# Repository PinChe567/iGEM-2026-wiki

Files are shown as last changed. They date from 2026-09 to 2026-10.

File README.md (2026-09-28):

# AeroSense Wiki · September 24 design edition

新版入口是 `index.html`。在此資料夾執行 `./preview.ps1` 可開啟本機預覽，網址為 `http://127.0.0.1:8000/index.html`；若 8000 已使用，可執行 `./preview.ps1 -Port 8001`。不需要安裝網站套件。

最新修正記錄在上一層的 `reports/06-3D影片與介面修正版.md`。目前首頁載入 `homepage_animation/` 中新的 v3 Blender 雙影片，滾輪對應播放進度；Description 直接使用可左右控制的 3D 旅程；Parts 使用可點選的 Blender 受器模型。正式發布前仍需完成 iGEM 影片託管及 URL 串接。

美術微調在 `css/refinement.css`，共用果蠅與影片在 `js/experience.js`。`models/blender/` 保存可編輯的 v3 `.blend` 和建模／渲染腳本。header/footer 的共用來源為 `templates/`，修改後執行上一層 `scripts/sync_shell.py`。研究內文與原始 Markdown 保留。`run_windows.ps1` 是下列舊 v2 Blender 工作流程，**不是網站預覽啟動器**。

---

# 原始 AeroSense Showcase v2 文件

這版針對目前 interactive 的主要問題重新設計 Blender scene：

- 果蠅改成 rear-dorsal chase 用模型，翅膀 pivot 與身體連在胸部。
- Warehouse 有貨架、咖啡袋、咖啡豆、木箱、燈具、障礙物、實際 VOC source。
- Olfaction 不再是一堆圈圈，而是一個 antenna/sensilla corridor + 明確 receptor gateway。
- Cell 是單一大型 HEK293T-like cell chamber，含 receptor、Ca²⁺ 路徑、GCaMP signal。
- Hardware 是 sample chamber → PD → TIA → ADC → MCU 的 PCB 場景。
- Decoder 是 AL glomeruli → projection → sparse KC field，不再用不明圓圈。
- Return 回到 stored-food application。

## 執行

直接雙擊 `run_windows.bat`，或 PowerShell：

```powershell
powershell -ExecutionPolicy Bypass -File .\run_windows.ps1
```

輸出位置：

```text
models/showcase_v2/aerosense_fly_v2.glb
models/showcase_v2/aerosense_01_warehouse_v2.glb
models/showcase_v2/aerosense_02_olfaction_v2.glb
models/showcase_v2/aerosense_03_cell_v2.glb
models/showcase_v2/aerosense_04_hardware_v2.glb
models/showcase_v2/aerosense_05_decoder_v2.glb
models/showcase_v2/aerosense_06_return_v2.glb
models/previews_v2/*.png
models/blender/AeroSense_Showcase_v2.blend
```

生成後，把 `CURSOR_PROMPT_V2.txt` 給 Cursor，讓它把新版模型、穩定 chase camera、manual/autopilot、real-time score、stage dive、文字動畫一起接進前端。

> 注意：此環境無 Blender runtime，因此腳本已做 Python syntax check，但最終 render/API 相容性仍需你本機 Blender 跑一次。若有 Blender 5.2 API error，把完整 traceback 貼回來即可修。

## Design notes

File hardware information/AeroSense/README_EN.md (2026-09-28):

# AeroSense engineering package

Start here, then read `docs/EN/Assembly_Manual_EN.pdf`. This is a reproducible engineering prototype with executed simulations, compiled firmware and an operable demo UI. The PCB is not fabricated. Board operation, biological compatibility and odor-recognition performance have not been established.

## Files

|Purpose|Location|
|---|---|
|Print meshes, CAD, drawings|`STL/`, `CAD/`, `docs/EN/Design_Drawings_EN.pdf`|
|Simulation analysis and numerical results|`docs/EN/Simulation_Analysis_EN.pdf`, `results/`|
|Reproduce calculations/figures/movies|`reproduce.py`, `simulation/`, `requirements.txt`|
|Printed, purchased and PCB BOM|`BOM/BOM_EN.xlsx`|
|Assembly|`docs/EN/Assembly_Manual_EN.pdf`|
|UI, firmware, server|`software/`, `docs/EN/Software_Guide_EN.pdf`|
|Operation, normalization, performance|`docs/EN/Operating_Protocols_EN.pdf`|
|Feedback form|`docs/EN/User_Feedback_EN.pdf`|

Each document has Chinese and editable Markdown versions. `manifest.json` provides SHA-256 hashes. Original vendor PDFs and papers are referenced, not redistributed.

## Quick start

Run `python software/server/server.py --demo` from the package root. On the same computer, open `http://127.0.0.1:8765`, enter API key `local-demo-key`, connect and start. All records are explicitly DEMO. This does not operate a PCB.

Print one well for dimensional/material screening before committing to the large enclosure. The baseline has eight parts. The accessible cap replaces one cap with two, giving nine operating prints. Do not purchase both configurations as additive assemblies.

Ask the vendor to complete `validation/fit_measurements.csv` and provide a populated STEP model. Nominal fit is not guaranteed physical clearance. Start electronics with LEDs off; only set `BOARD_VALIDATED=true` after measured power, ADC and LED-waveform checks.

## Materials

|Part|Quantity|Resin|
|---|---:|---|
|01 body, 03 lid, 04 cap|1 each|Rigid PC/GF-like Black|
|02 tray|1|Aqua 8K Gray|
|05 monolithic wells|4|Aqua Clear Plus; fit/material test only, not qualified for direct HEK293T culture|

Both well-floor surfaces are flat, 0.5 mm thick; nominal fill is 150 uL. Flat floors do not ensure uniform illumination. Polishing does not remove bulk purple absorption or autofluorescence; measure transmission/background at the relevant excitation/emission wavelengths and change materials or culture-vessel architecture if unacceptable.

## Reproduction

Python 3.12 is recommended. Install `python -m pip install -r requirements.txt` in an isolated environment. From the extracted root:

```text
python reproduce.py --out ../AeroSense_replot --plots
python reproduce.py --out ../AeroSense_movies --video
python reproduce.py --out ../AeroSense_optics --optics
python reproduce.py --out ../AeroSense_flow --flow --engine csharp --workers 2
python reproduce.py --out ../AeroSense_cad --cad
```

`--out` must be a new directory. Full optical/CFD calculations can be lengthy. CFD runs 27 plate cases plus one no-plate control. The Windows C# accelerator builds from included source using the .NET Framework compiler. Use `--engine numpy` elsewhere, with lower speed. CAD requires OpenSCAD; a non-default location can be supplied to `python CAD/build.py --out new_directory --openscad executable_path`. The CAD combines parametric CSG and canonical meshes; it is not a fully parametric reconstruction of the vendor PCB.

Additional baseline mesh refinement (0.3/0.2 mm results already included):

```text
python simulation/flow_sweep.py --case base --dx .3 --engine csharp --max-steps 60000
python simulation/flow_sweep.py --case base --dx .2 --engine csharp --max-steps 60000
```

Converged files are resume-safe and skipped. Use a fresh output directory for genuine recalculation. Movies advect passive markers in stored steady fields, not time-dependent Navier–Stokes, cell shear, dissolution or growth.

Figure I estimates source-to-PD collection fraction; Figure J multiplies emission fluence rate by collection fraction. Neither is normalized arbitrarily to make the image resemble the paper. Different geometry, media and filters imply different fields and magnitudes.

## Evidence and limits

Executed: 24 optical conditions with three seeds, 247 collection-map points, 27 plate CFD cases plus control, 48 synthetic DLIA cases, UI/API/calibration/model code tests, firmware and LittleFS builds. Validation records distinguish these from physical testing.

All plate cases have higher mean four-well headspace speed than the no-plate control under the stated metric. Mesh independence is not established. Do not claim cell protection from these calculations.

PD offset is modeled, while its signed direction still requires vendor rotation/mirroring confirmation. Wells follow LEDs; they are not forced into exact 90-degree radial spacing about the PD. Four frequency amplitudes from one PD are LED channels, not automatically independent well signals. Measure the optical mixing matrix before unmixing.

The neural-network training/held-out-group/inference pipeline is supplied without a fabricated trained model or odor accuracy. Templates are under `software/templates/`. No cloud account or external deployment has been created; internet access requires HTTPS and authentication configuration.

Known partial device cost is TWD66,749–67,182 including this quote's allocated PCB design/setup. Essential optical/gas items and shared equipment remain unquoted; this is not a complete or production cost.

The package supports wiki design, methods and simulation evidence. Add real photographs, calibration curves, cell data, independent-batch evaluation and participant feedback before claiming demonstrated hardware performance. Select the team's publication licenses and check third-party rights before public release.

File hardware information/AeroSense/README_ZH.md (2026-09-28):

# AeroSense 完整工程交付

先讀本檔，再讀 `docs/ZH/Assembly_Manual_ZH.pdf`。本套件是可重現的工程原型：有實際執行的模擬、可編譯韌體和可操作示範 UI；PCB 尚未製造，沒有實板、細胞或氣味辨識效能驗證。不要把模型圖當成實物照片。

## 檔案入口

|工作|檔案|
|---|---|
|列印與設計|`STL/`、`CAD/`、`docs/ZH/Design_Drawings_ZH.pdf`|
|光學、氣流與 DLIA 結果|`docs/ZH/Simulation_Analysis_ZH.pdf`、`results/`|
|重跑與重畫|`reproduce.py`、`simulation/`、`requirements.txt`|
|採購、列印材料、PCB 子料|`BOM/BOM_ZH.xlsx`；四個工作表分開，不重複計入 PCB 報價|
|組裝|`docs/ZH/Assembly_Manual_ZH.pdf`|
|手機 UI、ESP32、伺服器|`software/`、`docs/ZH/Software_Guide_ZH.pdf`|
|操作、校正與性能驗證|`docs/ZH/Operating_Protocols_ZH.pdf`|
|使用者回饋|`docs/ZH/User_Feedback_ZH.pdf`|

每份文件都有英文版與可編輯 Markdown；`manifest.json` 可核對檔案 SHA-256。使用者來源 PDF/論文本身沒有重新散布。

## 最快開始

1. 先執行手機介面的示範：在套件根目錄執行 `python software/server/server.py --demo`，以同一台電腦瀏覽 `http://127.0.0.1:8765`，API key 輸入 `local-demo-key`。資料明確標記 DEMO，沒有連到實板。
2. 先印四井中的一個作尺寸／材料測試，再印大殼。預設共八件；可拆洗內蓋用兩件取代一件，總共九件。兩套內蓋不能同時累加採購。
3. 給廠商 `validation/fit_measurements.csv`，取得含元件 STEP、LED/PD 方向與最高點；尚無法保證「一定不撞件」。
4. 依操作流程先暗訊號、電子假負載、無細胞螢光標準，再做材料／细胞驗證。預設韌體只允許 LED 全關的暗量測；量測供電、ADC 與 LED 波形後才設定 `BOARD_VALIDATED=true`。

## 樹脂與列印數量

|零件|數量|樹脂|
|---|---:|---|
|01 殼體、03 外蓋、04 內蓋|各 1|Rigid PC/GF-like Black|
|02 底托|1|Aqua 8K Gray|
|05 四個獨立一體 well|4|Aqua Clear Plus，僅供尺寸及材料試驗，未確認可直接培養 HEK293T|

Well 內外底面都平，底厚 0.5 mm，名目 150 µL。紫色樹脂的吸收與自身螢光不能用拋光消除；需實測 470/520 nm 相關光譜與空白，通不過就換經測試的透明材料或細胞培養容器方案。平底可減少厚度變化，但不保證照明均勻。

## 重現計算

建議 Python 3.12，在獨立環境安裝 `python -m pip install -r requirements.txt`。以下命令從解壓後根目錄執行。`--out` 指定尚不存在的新資料夾，保留交付資料：

```text
python reproduce.py --out ../AeroSense_replot --plots
python reproduce.py --out ../AeroSense_movies --video
python reproduce.py --out ../AeroSense_optics --optics
python reproduce.py --out ../AeroSense_flow --flow --engine csharp --workers 2
python reproduce.py --out ../AeroSense_cad --cad
```

光學全跑需要較長時間；保存種子與每次能量帳本。CFD 全跑是 27 組孔板加 1 組無孔板，不是阻力公式替代。Windows C# 加速器由附帶原始碼編譯，需要系統 .NET Framework C# compiler；其他平台可用 `--engine numpy`，速度較慢。OpenSCAD 是 CAD 外部依賴，預設 Windows 標準安裝位置；非標準路徑直接用 `python CAD/build.py --out 新資料夾 --openscad 執行檔路徑`。

CFD 已附 0.3/0.2 mm 基準網格結果。額外重算網格細化：

```text
python simulation/flow_sweep.py --case base --dx .3 --engine csharp --max-steps 60000
python simulation/flow_sweep.py --case base --dx .2 --engine csharp --max-steps 60000
```

已收斂檔案會跳過；需要真正重算時用新的 `--out` 資料夾。不要直接覆寫交付資料。影片使用保存的定常速度場推進被動標記；不是非定常流體解，也沒有求細胞剪力、氣味溶解或生長。

圖 I 對應點光源到 PD 的收集比例，圖 J 是發射光 fluence rate × 收集比例；沒有把結果各自除以最大值來「畫得像論文」。本設計幾何、介質和濾片與論文不同，圖形及量級不應被強迫相同。

## 目前證據與尚未完成的驗證

- 已執行：24 光學條件×3種子、247 點收光圖、27 孔板+無孔板 CFD、48 合成 DLIA 案例、UI/API/校正與模型程式測試、韌體及網頁檔案系統編譯。
- 孔板案例在四井上方平均速度指標上都高於無孔板對照；網格獨立性尚未成立，不能以此保證保護細胞。
- PD 偏移已納入；正負方向仍由廠商封裝旋轉／底視鏡像確認。四井以 LED 配準；沒有假裝四個井中心恰好在 PD 周圍每隔 90°。
- 單一 PD 的四頻數值是 LED 頻道，不自動等於四井獨立訊號。先量實際混合矩陣，再判斷能否可靠解混。
- 神經網路提供訓練／獨立批次留出／推論程式，不提供虛構已訓練模型或辨識準確率。範本在 `software/templates/`。
- 光學濾片、氣體濾器與轉接等仍未完整報價；BOM 明確標「待報價」。目前已知單機部分成本約 NT$66,749–67,182，包含 PCB 此次設計／開機分攤，不是量產價。
- 手機直連 ESP32 與伺服器兩種路徑都有程式。未建立外部雲端帳戶、未公開部署；遠端網路使用需依軟體指南配置 HTTPS 與金鑰。

本套件可作 wiki 的設計、方法及模擬證據；實物照片、校正曲線、細胞資料、跨批次模型評估與他人組裝問卷必須以真實實驗補齊。`validation/` 的通過項目不能改寫成整台機器已驗證。

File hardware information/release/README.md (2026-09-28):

# Release BOM

`AeroSense_Reader_BOM.csv` is published here only after `scripts/check_hardware_bom.py` passes.

The current `pcb v2/NTHU_TEST_BOARD_BOM.docx` is a draft. See `../BOM_SOURCE_AUDIT.md`. Do not link that DOCX as the final BOM.

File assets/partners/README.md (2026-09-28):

# Partner logos

Place **licensed, locally hosted** logo files in this folder.

Collaborators & Sponsors appear as reserved logo slots in the footer and on the homepage. Do **not** hotlink external logos. Do **not** invent a mark. Do **not** link the slots to Attributions.

When a licensed file exists, put it inside the matching slot:

```html
<figure class="footer-partners__slot">
  <img src="assets/partners/ist-group.png" alt="iST Group" width="180" height="72">
  <figcaption>iST Group</figcaption>
</figure>
```

Use `alt` = organization name. The hatched placeholder hides automatically when an `<img>` is present.

## Files still required

These organizations are named on the wiki. Logo files are **not** in the repository yet.

| Suggested filename | Organization |
| --- | --- |
| `ist-group.svg` or `ist-group.png` | iST Group |
| `nthu.svg` or `nthu.png` | National Tsing Hua University |

Optional, only after permission or a compatible license is on file:

| Suggested filename | Organization | Note |
| --- | --- | --- |
| `igem.svg` or `igem.png` | iGEM Foundation | Use only with iGEM brand permission |
| `fiti.svg` or `fiti.png` | FITI | Mentorship; confirm logo use |
| `garage-plus.svg` or `garage-plus.png` | NTHU Garage+ | Mentorship; confirm logo use |

Until a file exists, leave the reserved slot empty. Do not add a fake logo.

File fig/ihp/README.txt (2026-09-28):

AeroSense IHP image drop folder
===============================
Place consented, project-specific assets here. Do not add stock photos.

Expected filenames (see human-practices.html TODO(imagery) comments):
  people/taoyuan.webp
  people/farmers.webp
  people/enose.webp
  people/challenge-bioproducts.webp
  people/instrumentation.webp
  people/fiti.webp
  people/garageplus.webp
  people/exporters.webp
  hero-field-or-sensor.webp
  visit-taoyuan-annotated.webp
  mentor-fiti-bp-excerpt.webp
  mentor-fiti-pitch-excerpt.webp
  survey-*.webp (optional; HTML bars are primary)
  event-synbiobeta-poster.webp
  prototype-reader-bench.webp
  ui-risk-tier-shipped.webp (only if real UI exists)
  current-state.svg (optional export)
  problem-quant-sourced.svg (only with locked citation)

Each file needs: useful alt text in HTML, figcaption with context, credit/source, optimized size, lazy loading below the fold.

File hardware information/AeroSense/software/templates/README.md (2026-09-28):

D1–D4 are calibrated deltaF/F0 LED-channel features, not automatically unmixed wells.
Each group must represent an independent cell batch/day/device, never windows from the same exposure.
D1–D4 是 LED 通道 ΔF/F0；group 必須以獨立細胞批次／日期／設備分組，不能拆同一次刺激的時間窗。

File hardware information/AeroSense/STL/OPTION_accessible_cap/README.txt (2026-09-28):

Replace the one-piece 04 cap with BOTH files here: total operating prints = 9. Two M3x12 thumbscrews replace M3x10. Extra silicone ring: 22x19 outer,15x12 opening,0.8 stock compressed to0.6 mm. Cleaning/cure access improves, but biocompatibility and sealing are NOT validated. Do not print both cap options for one device.

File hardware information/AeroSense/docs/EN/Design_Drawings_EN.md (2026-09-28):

# Assembly and registration drawings

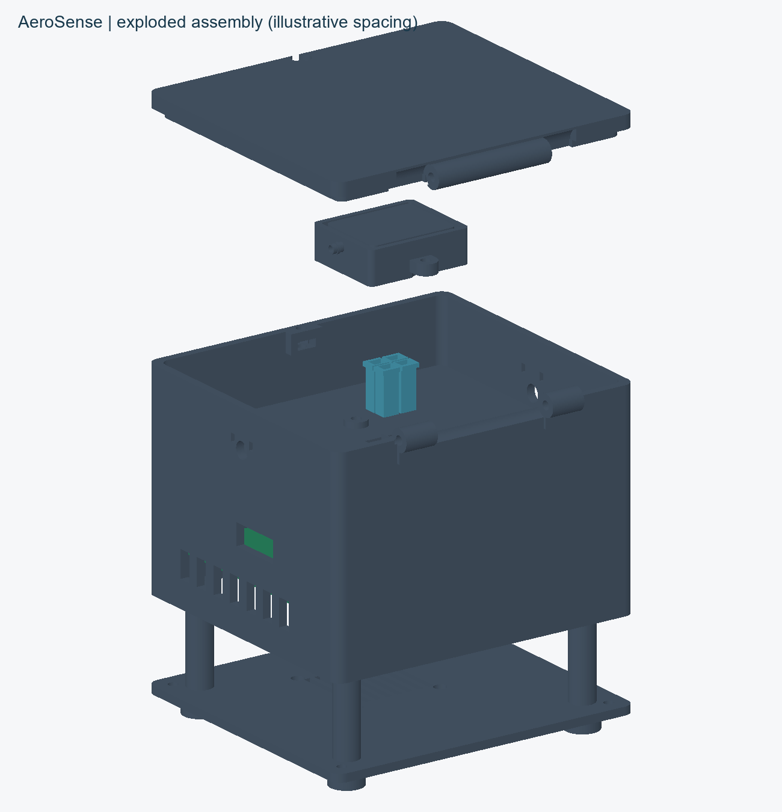
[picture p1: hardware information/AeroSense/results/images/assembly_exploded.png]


Exploded spacing is illustrative; actual placement is in CAD/assembly_coordinates and parts.json. Nominal overall bounds114 x109 x91 mm exclude hoses/fasteners. Units:mm. Part sheets show views/envelopes, not a complete GD&T manufacturing drawing.

# LED and PD optical registration

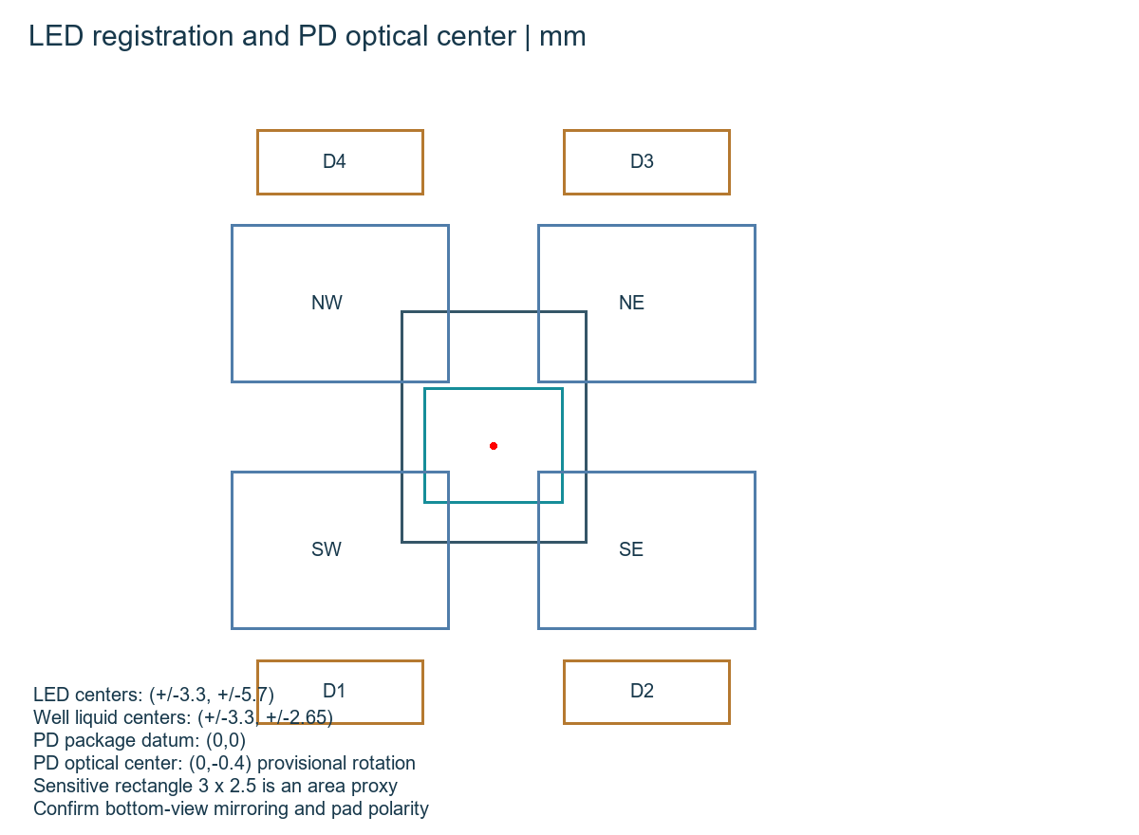
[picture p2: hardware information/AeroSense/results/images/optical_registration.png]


PD offset0.4 mm and LED-based well registration are independent. Package orientation, mounting holes and heights still require vendor STEP. Decimal display does not establish +/-0.01 mm accuracy.

# 01_integrated_body

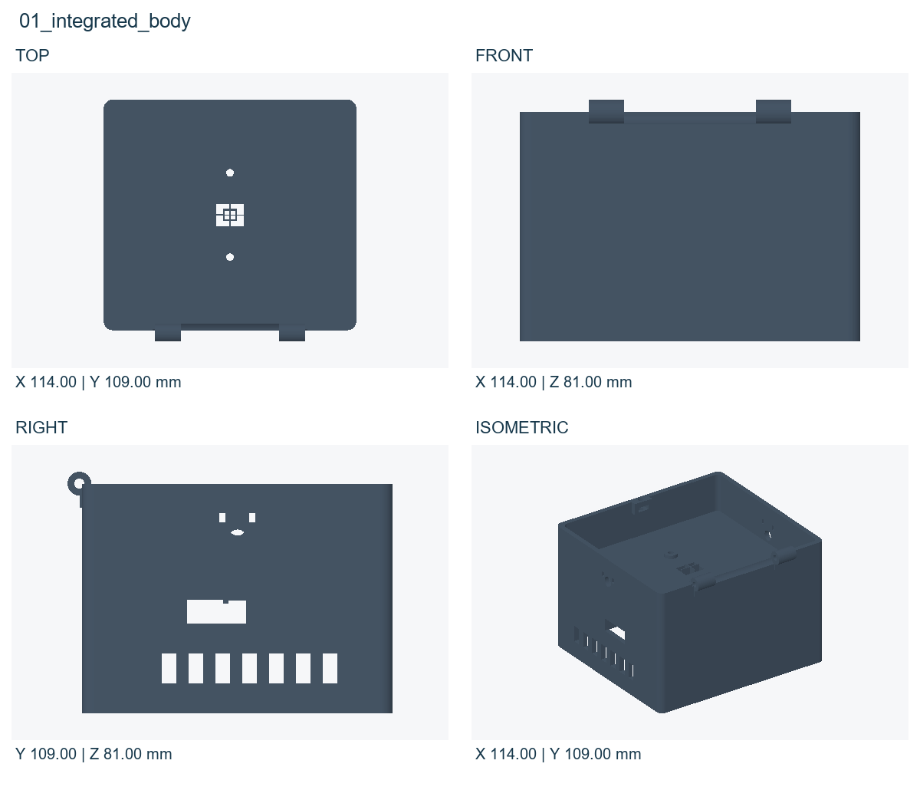
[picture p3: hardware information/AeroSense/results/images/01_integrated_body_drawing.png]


Material:PC_GF_BLACK. Assembly minimum(mm):[-57.0, -52.0, 3.0]. Printable STLs are translated to positive coordinates; do not assemble them by overlapping print origins.

# 02_service_tray

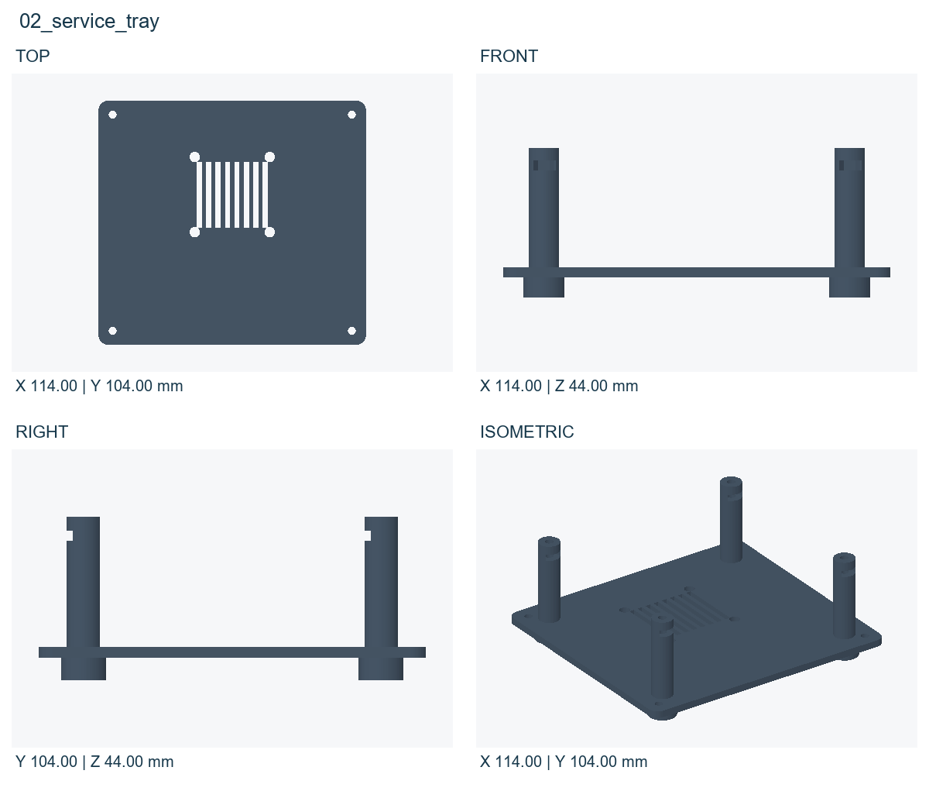
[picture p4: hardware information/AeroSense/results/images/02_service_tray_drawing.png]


Material:AQUA_8K_GRAY. Assembly minimum(mm):[-57.0, -52.0, -6.0]. Printable STLs are translated to positive coordinates; do not assemble them by overlapping print origins.

# 03_hinged_lid

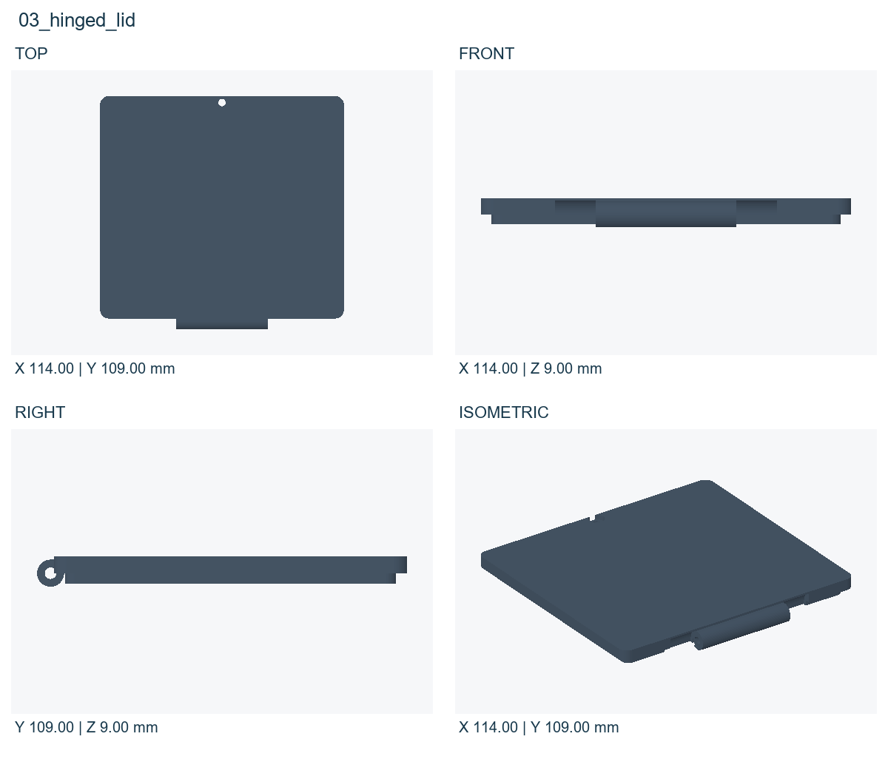
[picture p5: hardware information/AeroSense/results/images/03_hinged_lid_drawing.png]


Material:PC_GF_BLACK. Assembly minimum(mm):[-57.0, -52.0, 76.0]. Printable STLs are translated to positive coordinates; do not assemble them by overlapping print origins.

# 05_well_NE_CLEAR

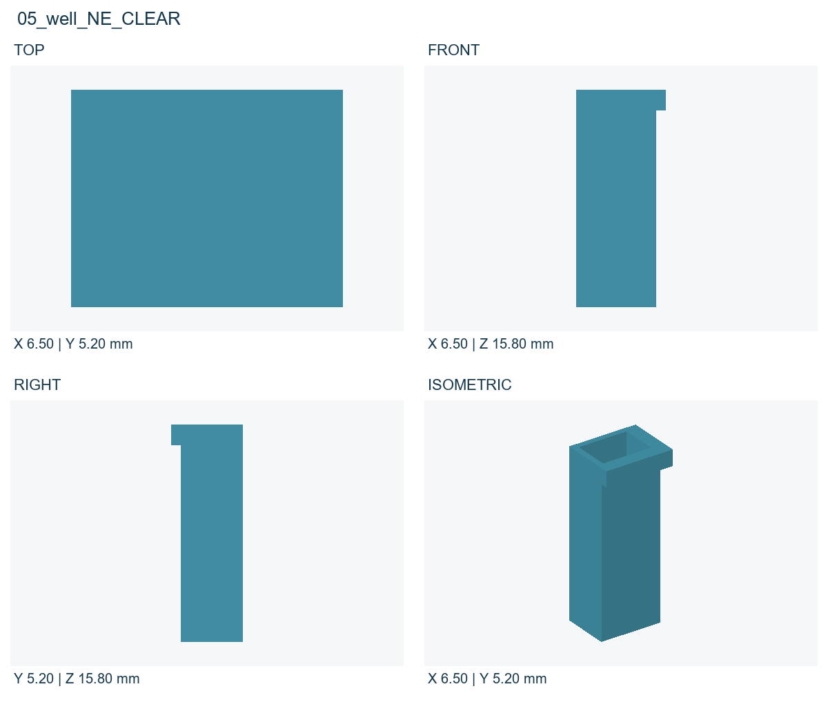
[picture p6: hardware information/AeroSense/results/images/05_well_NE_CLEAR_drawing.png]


Material:AQUA_CLEAR_PLUS_TEST_ONLY. Assembly minimum(mm):[0.4, 0.4, 42.5]. Printable STLs are translated to positive coordinates; do not assemble them by overlapping print origins.

# 05_well_NW_CLEAR

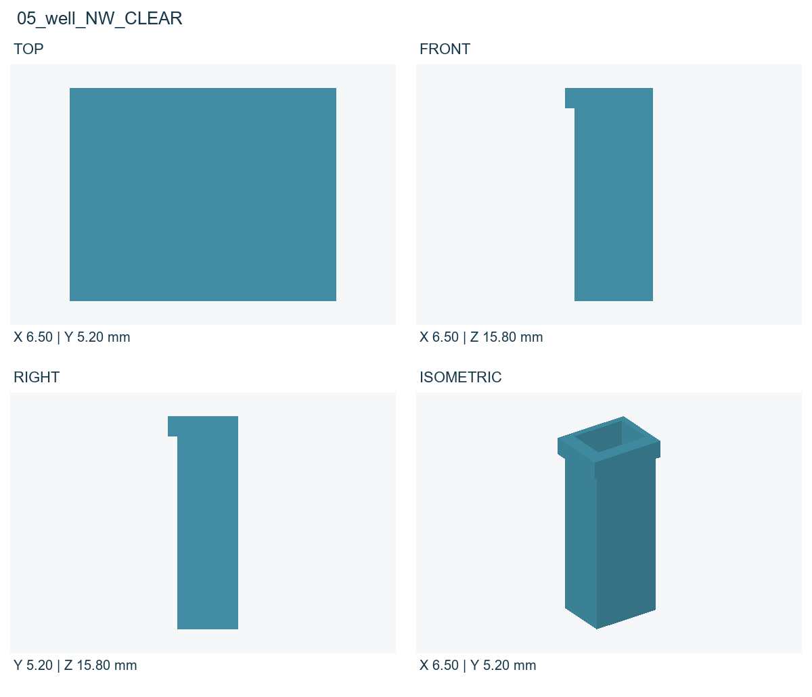
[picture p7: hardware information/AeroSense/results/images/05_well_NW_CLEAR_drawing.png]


Material:AQUA_CLEAR_PLUS_TEST_ONLY. Assembly minimum(mm):[-6.9, 0.4, 42.5]. Printable STLs are translated to positive coordinates; do not assemble them by overlapping print origins.

# 05_well_SW_CLEAR

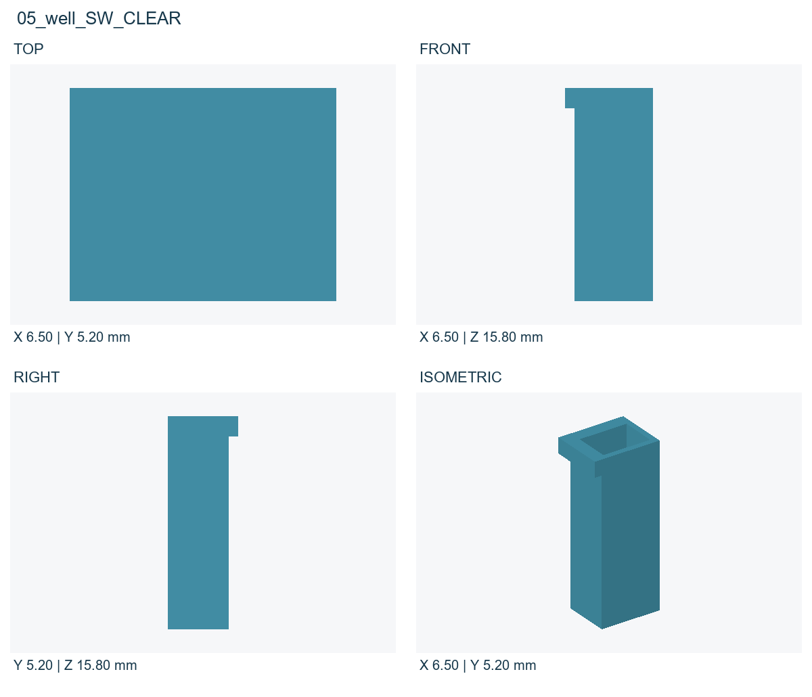
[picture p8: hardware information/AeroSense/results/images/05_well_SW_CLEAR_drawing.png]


Material:AQUA_CLEAR_PLUS_TEST_ONLY. Assembly minimum(mm):[-6.9, -5.6, 42.5]. Printable STLs are translated to positive coordinates; do not assemble them by overlapping print origins.

# 05_well_SE_CLEAR

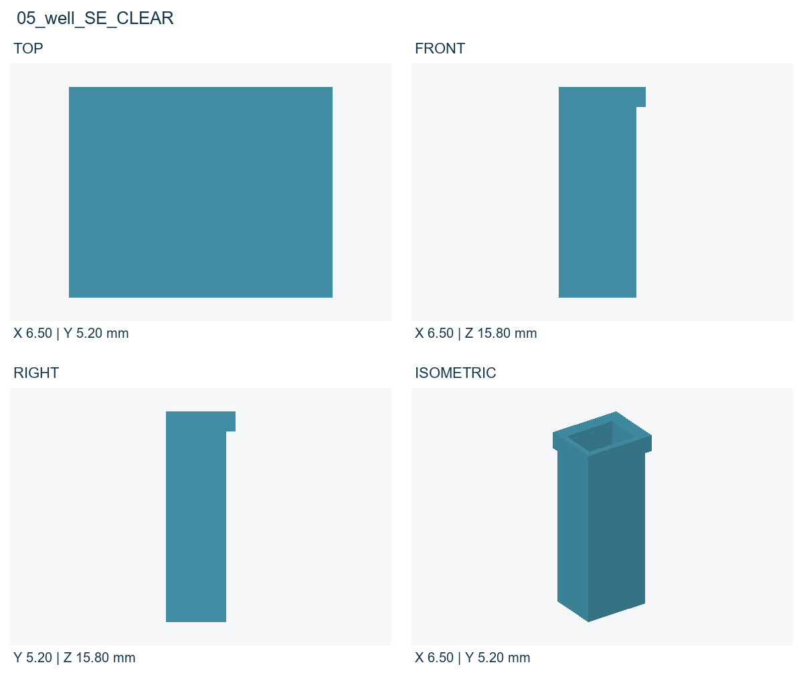
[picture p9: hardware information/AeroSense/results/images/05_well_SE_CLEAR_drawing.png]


Material:AQUA_CLEAR_PLUS_TEST_ONLY. Assembly minimum(mm):[0.4, -5.6, 42.5]. Printable STLs are translated to positive coordinates; do not assemble them by overlapping print origins.

# 04_common_gas_optical_cap

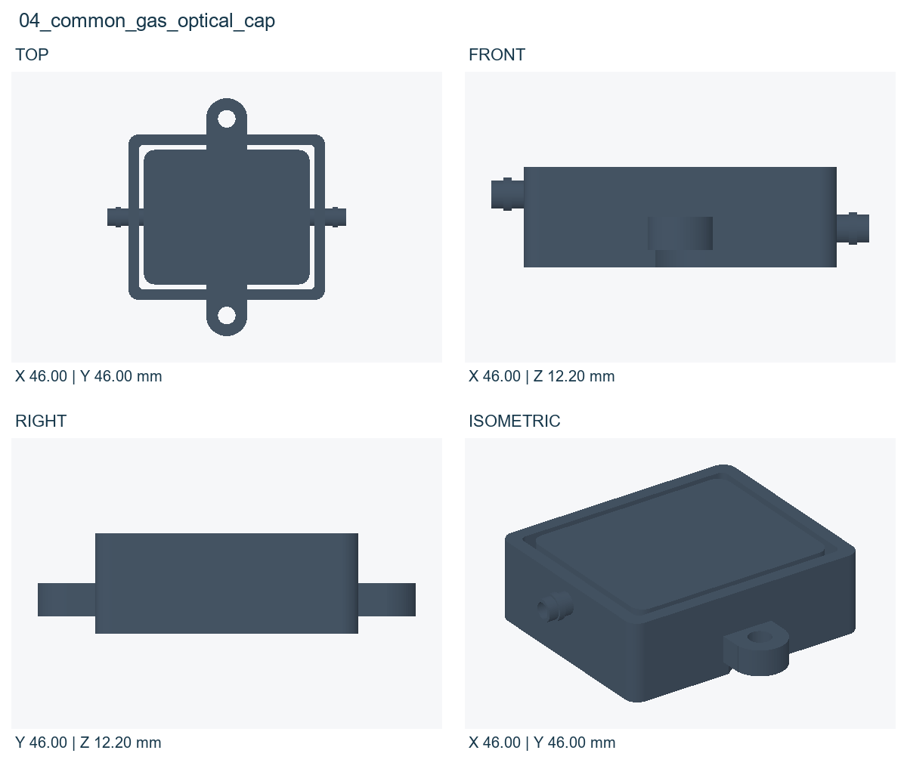
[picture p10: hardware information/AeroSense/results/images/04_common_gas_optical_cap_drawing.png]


Material:PC_GF_BLACK. Assembly minimum(mm):[-23.0, -23.0, 56.8]. Printable STLs are translated to positive coordinates; do not assemble them by overlapping print origins.

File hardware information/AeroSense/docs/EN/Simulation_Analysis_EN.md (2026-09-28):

# AeroSense engineering analysis

This report separates CAD, physical assumptions, numerical solutions and experimental evidence. Completed: flat-well STLs,24 photon-transport conditions,27 perforated-plate CFD cases plus no-plate control, spatial optical/acceptance maps,48 synthetic DLIA tests, phone UI and compiled ESP32 source. Pending: actual PCB operation, physical fit, sealing, resin/cell compatibility and odor-classification performance.



Conclusion: the PCB provides four LED gates and one16-bit ADC path for a four-frequency system. Adequate optical throughput, viable cells and independent well recovery still require experiments. Low part count and appearance do not substitute for validation.

# Geometry, optical center and tolerance



Wells register to the corresponding LED X coordinates and preserve clearance from dense components, rather than forming four equal round wells about the PD package center. Both well floors are planar with0.5 mm thickness and150 uL nominal fill. Flatness controls thickness but does not remove angular illumination, reflection or cell-distribution nonuniformity.

The Vishay drawing establishes a0.4 mm long-axis offset; the world sign depends on bottom-view mirroring and placement rotation. Main model:(0,-0.4), with(0,0),(0,+0.4), andX±0.2 sweeps. A3 x2.5 mm equal-area sensitive rectangle is used; the external3 x3 mm window is not assumed to be the active die. The nominal filter seat covers it, while gasket clipping needs measurement.

Four quadrants do not imply exactly90-degree spacing of well-center vectors, nor a fixed90-degree angle for every LED-cell-PD ray. Side excitation/downward collection is the design intent; the MC uses angular distributions.

# Optical method and correspondence to the paper

The plots follow Burton et al. Fig.2 I/J concepts, but that halo cannot be copied as this device result. Their miniature LED/PD, filter, dye solution and dimensions differ. This model uses millimeter resin wells and a20 um floor-cell layer.

η(r) is received power divided by power emitted by an isotropic point source, not peak normalization. Φ is weighted track-length per voxel volume, a scalar fluence rate in uW/mm2. J=Φ_em xη is the paper-style comparison. Source-position contribution uses q_em xη integrated over volume; these are different quantities and units.

Transport includes Beer-Lambert absorption, Henyey-Greenstein scattering, Fresnel refraction/reflection/TIR, diffuse opaque-wall reflection and two-stage fluorescence. Assumptions:470/520 nm,500 uW LED,QY1, cell absorption0.5/mm and20 um cell layer; emitted power includes470/520. Resin n1.5, liquid n1.333. The1 mm absorbing filter proxy is not a measured multilayer angular response.

Geometry is rectilinear CSG corresponding to CAD, not arbitrary STL triangle tracing. Upper cap holes use equal-area squares. Lens shape, roughness, resin autofluorescence, spectra, cell expression, PD spectral responsivity and electronic noise are not included in transport predictions.

# Spatial acceptance and fluence results

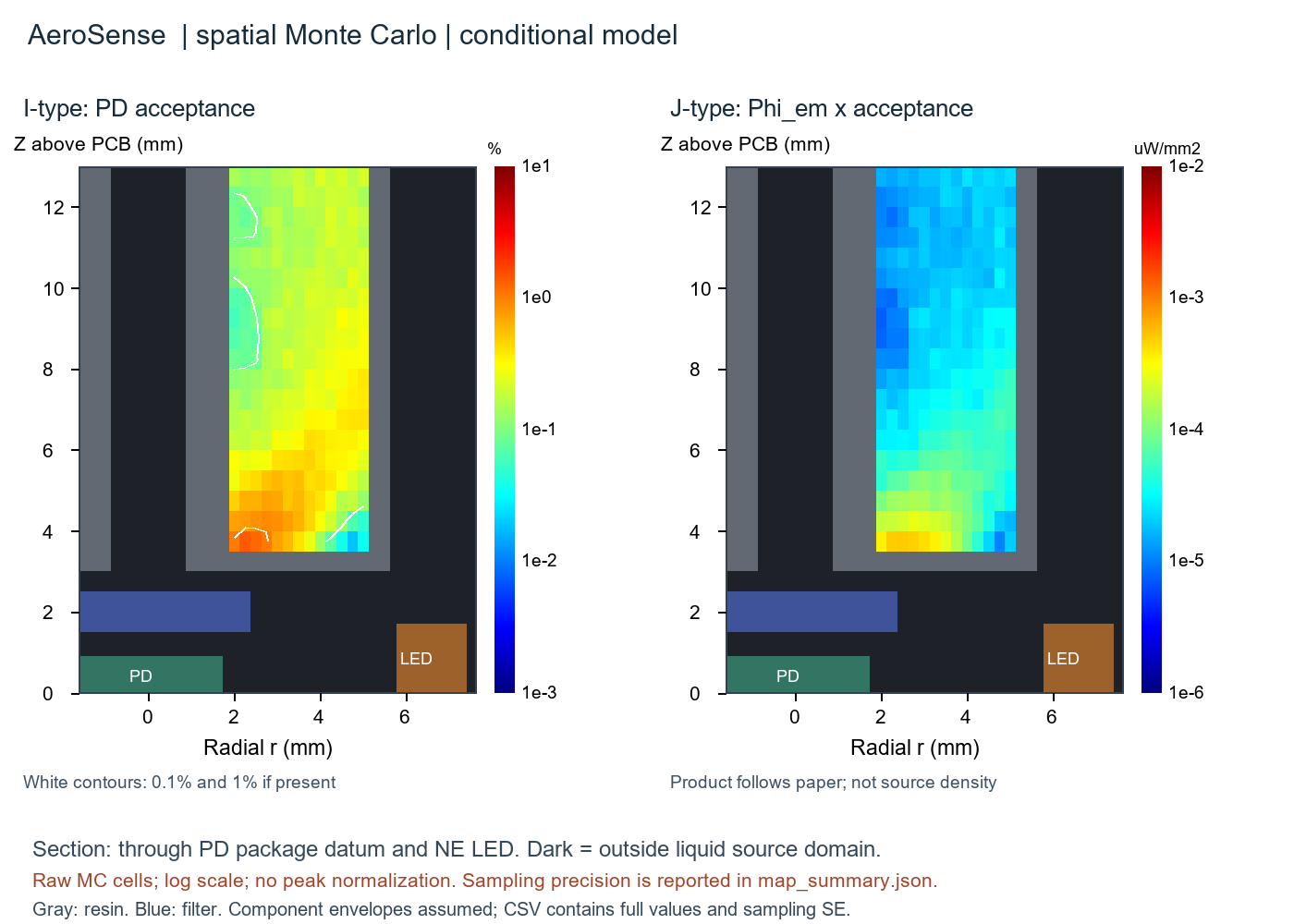
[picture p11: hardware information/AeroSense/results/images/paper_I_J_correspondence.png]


247 liquid source positions x32,768 packets =8,093,696 packets. Maximum η=1.398%; median relative SE=11.3%;3 points exceed25%. No peak normalization. Maximum J=0.000503 uW/mm2. Gray/dark areas are outside the liquid-source domain, not uncomputed values filled with zero.

Spatial fluence uses3 seeds, each40,000 excitation and100,000 emission packets. Received green power in this calculation is0.657 +/-0.058 nW (mean +/- MC SE). This is conditional power, not a measurement or biological prediction interval.

# 24 optical parameter conditions

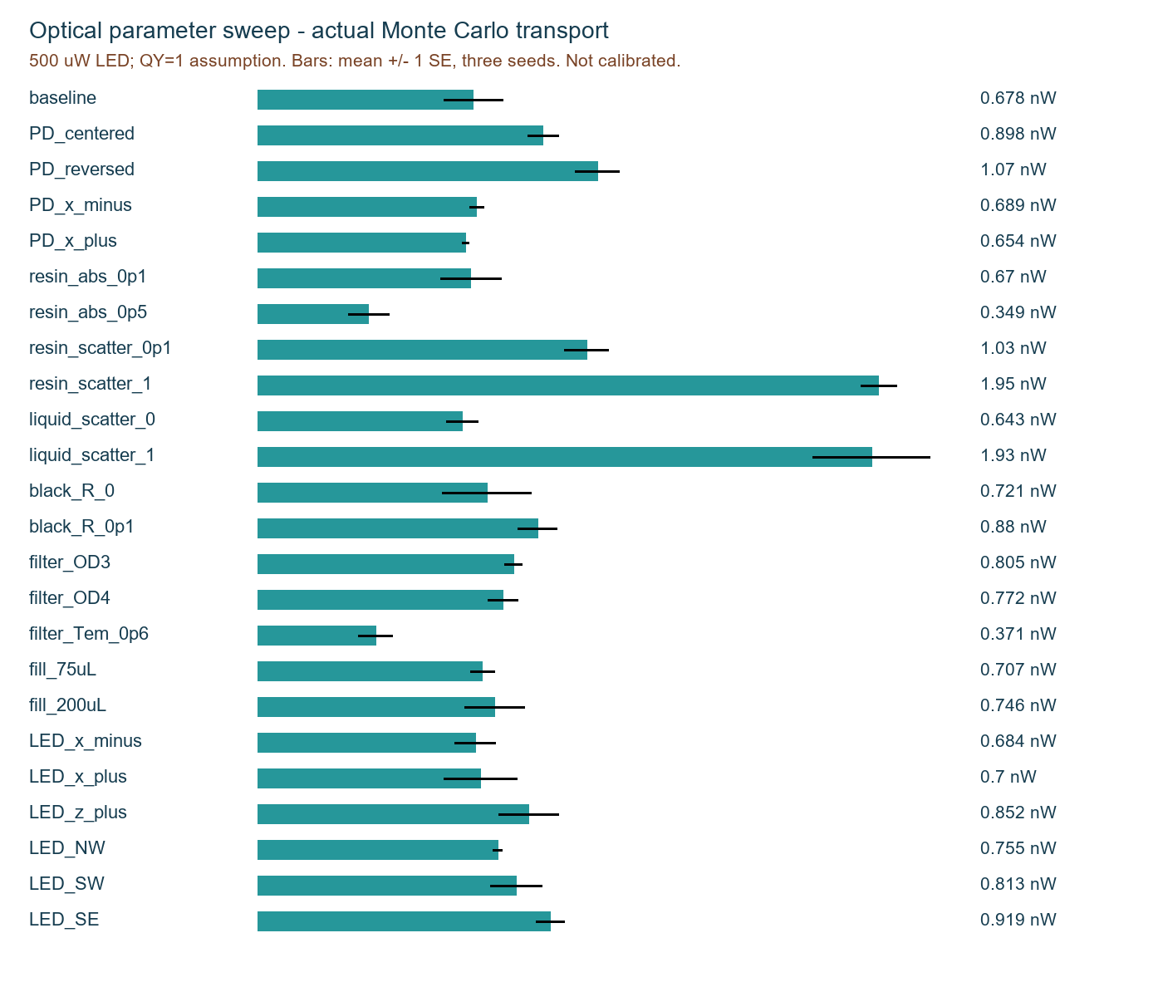
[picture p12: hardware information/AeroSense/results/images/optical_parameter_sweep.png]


Each condition has3 seeds x(16,000 excitation+40,000 emission) packets:4,032,000 total. Factors cover detector offsets, resin absorption/scatter, liquid scatter, wall reflection, filter OD/transmission,75/150/200 uL, emitter offsets and all LEDs. Per-seed ledgers, CSV, SE and plotting code are supplied.

Detector reversal materially changes the result; arbitrary centering is inappropriate. Some weak-absorption/small-offset differences are below MC precision and should not be ranked. More scattering may increase collection and crosstalk in this geometry, not justify deliberately cloudy resin. Zero sampled crosstalk is not proof of physical isolation.

# Is the signal sufficient?

Sweep baseline:0.678 +/-0.092 nW; centered proxy0.898 +/-0.049 nW; reversed offset1.068 +/-0.069 nW. These compare sensitivity under common assumptions and do not establish actual placement orientation.

Scale example only: assuming responsivity0.3 A/W at520 nm,0.678 nW gives about0.203 nA and20.3 mV at ideal100 Mohm transimpedance. A2.5 V16-bit ADC LSB is38.15 uV. Unknown GCaMP quantity, QY, background, angular response and TIA noise may dominate; sufficient SNR or detection limit is not established.

Maximum sweep energy-ledger error is about4.44e-15: numerical accounting, not material validation. Tests include rectangular solid-angle acceptance, normal Fresnel0.04, TIR, HG mean angle, Beer-Lambert and homogeneous track length. Three-seed SE is limited; small differences require more seeds and paired analysis, not merely smooth plotting.

Simulated LED-by-well matrix condition number is about1.35, but it is not a hardware calibration matrix. Simulation row order isNE/NW/SW/SE; provisional firmwareD1/D2/D3/D4 mapsSW/SE/NE/NW. Measured M must include frequency gain/phase under matched cells, fill and optics.

# 27-condition airflow sweep

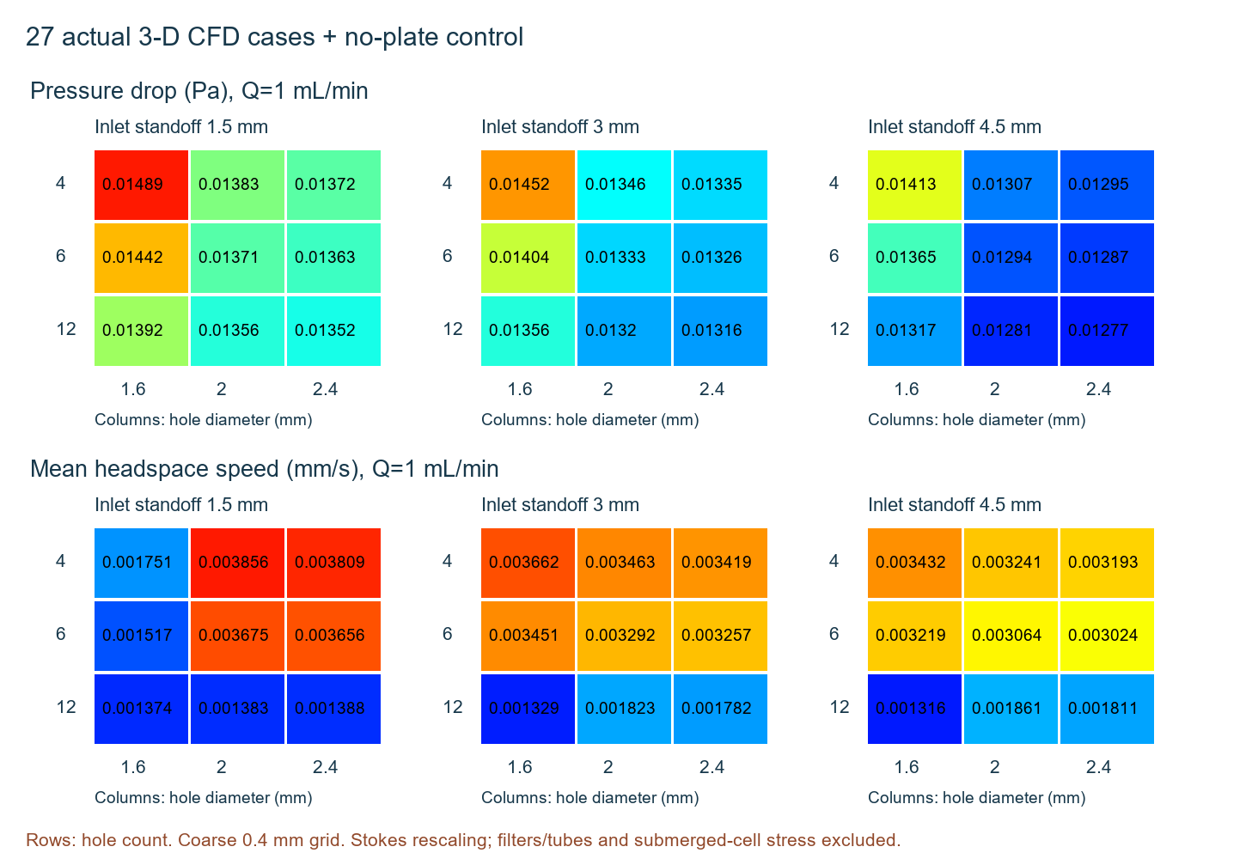
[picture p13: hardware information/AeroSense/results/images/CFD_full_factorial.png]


Diameter1.6/2.0/2.4 mm x4/6/12 holes x1.5/3/4.5 mm inlet-axis standoff gives27 full-factorial3-D CFD cases plus no-plate control on a common0.4 mm grid. Changing inlet height also changes upper-plenum volume; effects are not solely due to distance.

All28 cases meet the declared iteration criteria; maximum terminal mass imbalance is0.117%. Lowest plate-case mean well-headspace speed isgap_4p5:0.001316 mm/s at1 mL/min, versus0.00080951 without a plate. Every plate case is higher. This does not support a claim that the plate necessarily protects cells.

# CFD method, videos and limitations

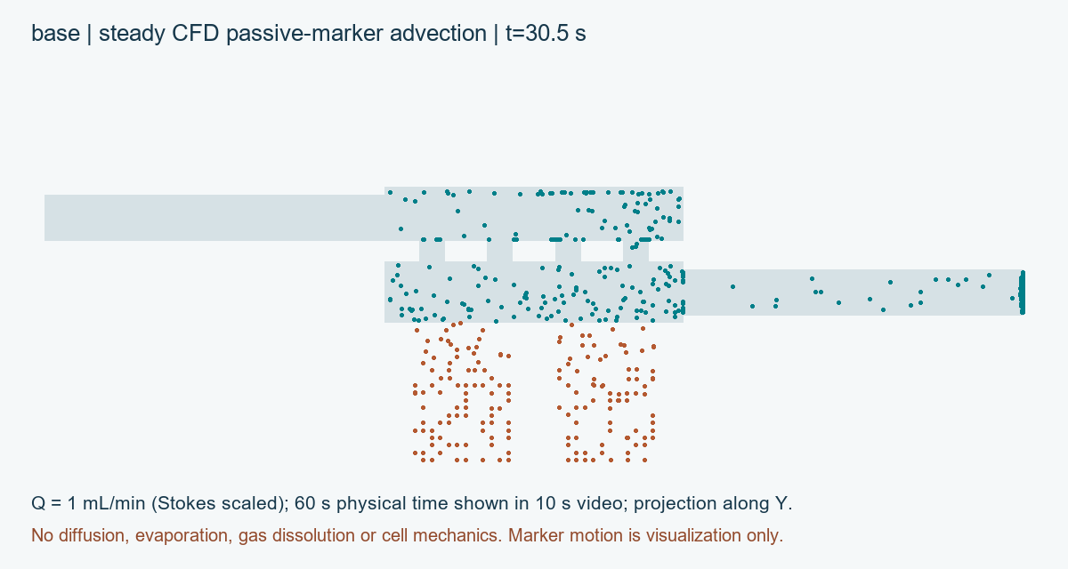
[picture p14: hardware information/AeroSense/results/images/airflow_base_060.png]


D3Q19 BGK lattice-Boltzmann,τ0.8, air density1.2 kg/m3 and viscosity1.8e-5 Pa s. No-slip solid/stationary-liquid boundaries and nonequilibrium-extrapolation pressure planes. The solver uses density difference0.001 at lowRe. Results at1 mL/min or0.01 Pa use Stokes scaling, not new nonlinear solves at those conditions.

Check every200 steps; require relative velocity change<2e-5 and terminal mass imbalance<0.2% for3 checks. Baseline pressure changes over0.4→0.3→0.2 mm are nonmonotonic (about-7.8%,+9.1%), with local velocity changes. Mesh independence is not established. Poiseuille and NumPy/C# comparisons are reproducible but do not eliminate voxelized circular-wall errors.

MP4s advect passive markers through saved steady fields:60 s physical time in10 s video, Y projection, nearest-voxel velocity and stopping at solids. No diffusion, liquid flow, odor dissolution, evaporation, oxygen transfer, cell shear or growth is solved. Videos do not establish cell safety, receptor exposure or a transfer time constant.

# Electronics and DLIA numerical checks

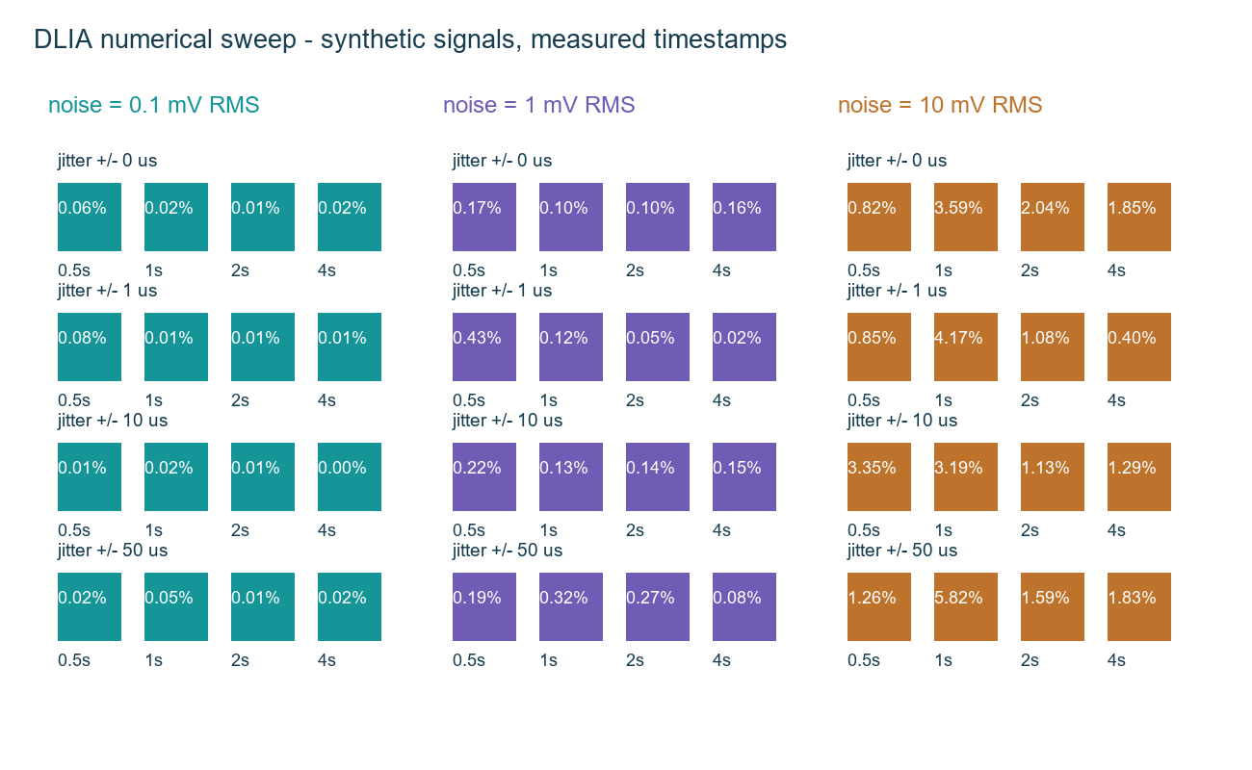
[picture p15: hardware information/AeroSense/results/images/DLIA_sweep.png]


LED1-4 gates areGPIO25/26/27/32; ADC SCLK18,DOUT19,CONVST33. Firmware uses one4 kHz hardware timebase for integer DDS gates and the sampling task, avoiding frequency overwrites from shared LEDC timers. A2 s I/Q window has8000 samples; ADC wait10 us, SPI2 MHz.

48 synthetic cases sweep0.5/1/2/4 s windows,0.1/1/10 mV noise and0/1/10/50 us timestamp perturbation. Maximum offline joint-LS relative amplitude error is5.82%, not board accuracy. At25% duty, simulated DDS cross-frequency leakage reaches0.71%; calibration is still required, not ideal orthogonality.

The simplified100 Mohm x2.2 pF feedback pole is about723 Hz. Operating below it does not establish closed-loop stability or accuracy. Measure detector capacitance, parasitics, leakage, resistor voltage coefficient, ADC drive and Wi-Fi interference. An enclosure or firmware cannot compensate for a poor high-impedance TIA layout.

# Cost, iGEM evidence and publication boundaries

Estimated consumed resin for8 parts:TWD713.99; core hardware/fan269.70–452.70; quoted/allowed gas-optical portion140–390. Filter, two gas filters, coupling kit and shared equipment remain unquoted. PCB quote:TWD131,250/2 boards including design/setup; average65,625 is not a production price. Known partial device cost:66,748.69–67,181.69, not a full total.

iGEM Hardware emphasizes useful function, testing, improvement over existing tools, reproducible documentation and usability by others. This package supplies drawings, code, BOM, manuals and survey; actual functionality and user responses remain unmeasured. No separate Overgrad-specific numerical hardware scoring formula is claimed.

Suggested wiki evidence: distinguish photographs/CAD, show LED/PD registration, I/J definitions, sweeps with SE, CFD controls/mesh limits, measured raw curves, independent assembly statistics and cost gaps. Trace requirement→calculation→build→test→iteration. Label unfinished work planned, not validated.

Before publication, check source attribution, third-party datasheet rights, team code licensing and personal data. Describe reproduced methods and assumed materials in Methods. Synthetic UI/NN tests are not odor-sensing performance.

# Sources and reproducibility

Primary geometry/wiring sources: supplied NTHU_TEST_BOARD_Schematic.pdf, TOP/BOT-0911.pdf and NTHU_TEST_BOARD_BOM.docx. PCB not fabricated; no vendor-certified populated STEP. Paper/SI were read from the supplied paper collection. Datasheets/official pages below support comparisons, not vendor endorsement.

Vishay VEMD5060X01 Rev1.2, package drawing and sensitive area
https://www.vishay.com/docs/84278/vemd5060x01.pdf

Wurth155124BS73200, side-view LED
https://www.we-online.com/components/products/datasheet/155124BS73200.pdf

TI ADS8866 RevC, 3-wire CS timing
https://www.ti.com/lit/ds/symlink/ads8866.pdf

TI LMP7721, amplifier design constraints
https://www.ti.com/lit/ds/symlink/lmp7721.pdf

Burton et al., PNAS2020, wireless photometry and supplied supplementary paper
https://pmc.ncbi.nlm.nih.gov/articles/PMC7022161/

iGEM special awards, Hardware
https://competition.igem.org/judging/special-prizes

Espressif LEDC timer sharing
https://docs.espressif.com/projects/esp-idf/en/v4.4.7/esp32/api-reference/peripherals/ledc.html

ATCC HEK293T CRL-3216 cell-line reference
https://www.atcc.org/products/crl-3216

Phrozen resin documentation index
https://helpcenter.phrozen3d.com/hc/en-us/articles/6485205777561-Manuals-and-Documentations

Package includes requirements, parameter settings, fixed seeds, raw CSV/NPZ, MC ledgers, CFD residuals, plotting and video code. manifest.json records SHA-256 per delivered file. Cross-platform floating-point differences should be assessed with statistical errors and declared tolerances, not bitwise equality.

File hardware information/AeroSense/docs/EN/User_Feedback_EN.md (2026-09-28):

# User feedback: participant record

Purpose: improve assembly, operation and documentation. Participation is voluntary; stop or skip at any time. No names, student numbers or contact details are collected. Obtain separate permission for photos, recordings or public quotations and follow institutional requirements for participant studies.

| Field | Response |
| Anonymous ID / date | ________________________ |
| Manual language / file hash | ZH / EN;________________ |
| Background | Biology / EE / mechanical / other________ |
| 3D assembly experience | None /1-3 projects /4+ |
| Prior AeroSense exposure | None / read / assembled |
| Board used | Dummy / real;________________ |
| Participation | Understands right to stop:yes / no |

Use dry parts and dummy/cell-free samples without pressurized gas. Use clearly labeled demo mode for UI tasks unless a separate verified hardware protocol applies. Observers avoid unsolicited coaching, respond to requested help and record it. Never force a part or take a risk.

# Task log and ratings

| Task | Seconds / completion / help / errors |
| Find all parts using BOM | ________________________ |
| Fit fan, PCB and enclosure | ________________________ |
| Identify wells and fit cap/tubes | ________________________ |
| Open, replace a well, close | ________________________ |
| Connect UI, start and stop | ________________________ |
| Recognize DEMO/invalid; export | ________________________ |

Rate1 strongly disagree,2 disagree,3 neutral,4 agree,5 strongly agree, orN/A. These are project-specific questions, not a validated SUS questionnaire; do not report a SUS score.

| Item | 1 2 3 4 5 N/A |
| I can identify each part and orientation | ________________ |
| Instructions/images are sufficient | ________________ |
| Fasteners/tools are accessible | ________________ |
| Replacing a well needs no excessive force | ________________ |
| Lid motion avoids tube pull/well contact | ________________ |
| I can identify inlet and exhaust | ________________ |
| UI state/errors are understandable | ________________ |
| I can distinguish demo/hardware data | ________________ |
| I would assemble again using this guide | ________________ |

# Open feedback and analysis plan

Least clear step/figure:________________________________________________
Hardest part / likely assembly error:_____________________________________
Which part/purchase could be removed, and why?____________________________
Which action raised collision/leak/contamination concerns?__________________
One improvement to prioritize:__________________________________________
Other comments:______________________________________________________

Observer logs damage, reversed parts, incomplete seating, missing washers, overtightening, tube strain and help requests. Predefine completion: all parts present/oriented, wells removable, connectors accessible and no visible mechanical load. Appearance alone is not completion.

Analysis: report participant backgrounds, completion rates, median/IQR time and error/help categories. Report per-item Likert distributions; N/A is not neutral. A five-novice pilot is formative, not proof of broad usability. Retest improvements with new participants to reduce learning effects.

For the wiki, trace feedback → design decision → retest result. Retain negative feedback and do not fabricate satisfaction, participant counts or questionnaire results. Anonymize quotations before publication.

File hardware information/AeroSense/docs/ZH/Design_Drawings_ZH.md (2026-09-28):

# 總裝與座標圖



爆炸間距只供說明，實際座標以CAD/assembly_coordinates與parts.json為準。名目外形114×109×91 mm，未含接管和五金突出。所有圖單位mm，零件圖是視圖與包络尺寸，並非完整GD&T製造圖。

# LED與PD光學對位



PD的0.4 mm偏移與well的LED定位是兩個獨立設定。封裝形狀、板孔與元件高度仍須廠商STEP確認；不要以這張圖推定精度已達±0.01 mm。

# 01_integrated_body



列印材料：PC_GF_BLACK。組裝座標最小點(mm)：[-57.0, -52.0, 3.0]。STL/檔案已平移至正座標；不能把所有print STL原點直接重疊組裝。

# 02_service_tray



列印材料：AQUA_8K_GRAY。組裝座標最小點(mm)：[-57.0, -52.0, -6.0]。STL/檔案已平移至正座標；不能把所有print STL原點直接重疊組裝。

# 03_hinged_lid



列印材料：PC_GF_BLACK。組裝座標最小點(mm)：[-57.0, -52.0, 76.0]。STL/檔案已平移至正座標；不能把所有print STL原點直接重疊組裝。

# 05_well_NE_CLEAR



列印材料：AQUA_CLEAR_PLUS_TEST_ONLY。組裝座標最小點(mm)：[0.4, 0.4, 42.5]。STL/檔案已平移至正座標；不能把所有print STL原點直接重疊組裝。

# 05_well_NW_CLEAR



列印材料：AQUA_CLEAR_PLUS_TEST_ONLY。組裝座標最小點(mm)：[-6.9, 0.4, 42.5]。STL/檔案已平移至正座標；不能把所有print STL原點直接重疊組裝。

# 05_well_SW_CLEAR



列印材料：AQUA_CLEAR_PLUS_TEST_ONLY。組裝座標最小點(mm)：[-6.9, -5.6, 42.5]。STL/檔案已平移至正座標；不能把所有print STL原點直接重疊組裝。

# 05_well_SE_CLEAR



列印材料：AQUA_CLEAR_PLUS_TEST_ONLY。組裝座標最小點(mm)：[0.4, -5.6, 42.5]。STL/檔案已平移至正座標；不能把所有print STL原點直接重疊組裝。

# 04_common_gas_optical_cap



列印材料：PC_GF_BLACK。組裝座標最小點(mm)：[-23.0, -23.0, 56.8]。STL/檔案已平移至正座標；不能把所有print STL原點直接重疊組裝。

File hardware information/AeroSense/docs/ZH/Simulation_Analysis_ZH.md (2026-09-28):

# AeroSense 工程分析報告

本報告將CAD、物理假設、數值解與實驗證據分開。已完成：平底井STL、24組光子傳輸參數條件、27組孔板CFD加無孔板對照、空間光場與感測接收圖、48組DLIA合成訊號測試、手機UI與可編譯ESP32程式。尚未完成：實板功能、實物配合、密封、樹脂／細胞相容與氣味辨識效能。



結論：原PCB具備四路LED驅動與一個16-bit ADC讀取路徑，可建置四頻系統；但「光路足夠、細胞可活、四井能分開量測」仍須實驗。低零件數與外觀不能取代驗證。

# 幾何、光學中心與公差



四井依各自LED的X座標定位，保留現有密集元件的避空；不是以PD封裝中心畫四個等距圓井。井底內外皆平，0.5 mm厚，名目150 µL。平底能控制幾何厚度，但斜入射、角度、反射與細胞分布仍會造成亮度不均。

PD偏移依Vishay圖面可確定是沿封裝長軸0.4 mm，但世界座標正負取決於BOTTOM圖鏡像及貼裝旋轉。主模型採(0,-0.4)，另算(0,0)、(0,+0.4)、X±0.2。感光區以3×2.5 mm等面積矩形近似，不把3×3 mm外部光窗當成全部有效die。名目filter座足以覆蓋，PD密封圈邊緣遮擋仍是實測項。

四井在四象限，不代表井中心向量每隔精確90度；也不能宣稱每一條LED→細胞→PD光線恆為90度。側向激發與向下收光是設計意圖，MC包含角分布。

# 光學方法與文獻圖的對應

參考Burton等人的Fig.2 I/J概念，但不能複製其halo作為本機結果：其微型LED/PD、濾片、染料溶液與尺寸均不同。本模型是毫米尺度透明井與底部20 µm細胞層，不是同一介質與幾何。

η(r)=該位置等向點源被PD接收的功率／點源發出功率，並非以圖的最大值除成100%。Φ由包裹權重沿路徑長度積分除以體素體積計得，單位µW/mm²，是scalar fluence rate。J=Φ_em×η供文獻式比較；真正來源位置的接收貢獻是q_em×η並在體積積分，兩者單位與物理量不同。

程式包含Beer-Lambert吸收、Henyey-Greenstein散射、Fresnel折射／反射／全反射、不透光面漫反射及二階段螢光發射。波長470/520 nm，LED500 µW、QY=1、細胞吸收0.5/mm、20 µm層均是假設；発射能量乘470/520。透明樹脂n=1.5、液體n=1.333。濾片用1 mm吸收體近似，不是實測多層干涉濾片角度響應。

幾何是與CAD對應的分段矩形CSG，不是任意STL三角面光追。上蓋圓孔以等面積方孔近似；射源透鏡、表面粗糙、樹脂自發螢光、波長分布、細胞表達、PD光譜响应及電子噪聲不在傳輸結果內。

# 空間接收與光通量結果



247個液體點源，每點32,768包，共8,093,696包；η最大1.398%，中位相對標準誤11.3%，3點超過25%。不是峰值100%的彩圖。J最大0.000503 µW/mm²。灰／暗區表示不在可放液體點源的區域，不是把未模擬位置填0。

空間fluence採3個獨立種子，各40,000激發與100,000發射包。該計算的PD綠光接收為0.657±0.058 nW（平均±MC標準誤）。這是條件性功率，不是實測或生物預測信賴區間。

# 24組光學參數掃描



每條件3種子，每種子16,000激發+40,000發射包，共4,032,000包。掃PD偏移、樹脂吸收／散射、液體散射、黑面反射、濾片OD／透過、75/150/200 µL、LED位置偏差及四顆LED。附每種子帳本、CSV、SE和畫圖程式。

PD方向翻轉的結果差異大，證實不可任意置中；弱吸收與小位置偏差的差別有些小於MC誤差，不宜排名。大幅增加散射可能提高本幾何的收光，同時增加串擾，不代表應把樹脂故意做混濁。部分零串擾是有限抽樣的零事件，不是物理上完全隔離。

# 訊號是否足夠：可說與不可說

參數掃描基準為0.678±0.092 nW；PD置中情境0.898±0.049 nW，反向偏移1.068±0.069 nW。這些是相同物理假設下的敏感度比較，不是選定真實旋轉方向的證據。

只作量級示例：若520 nm responsivity=0.3 A/W（此處是假設），0.678 nW約產生0.203 nA，理想100 MΩ轉阻約20.3 mV。2.5V／16-bit ADC一LSB約38.15 µV。但未知GCaMP量、QY、材料背景、PD角度響應與TIA噪聲可能完全改變結果，因此不能宣稱本機已達足夠SNR或檢出限。

MC能量帳本最大誤差約4.44×10^-15；這驗證數值記帳，不驗證輸入材料。已做矩形接受立體角、Fresnel正入射0.04、全反射、HG平均角、Beer-Lambert與均勻介質track-length測試。三種子SE仍有限，細微參數差應增加種子並用成對統計，不把一張平滑圖當精度證明。

模擬LED×well傳輸矩陣條件數約1.35，但這不是可燒入實機的校正矩陣。其列順序NE/NW/SW/SE，韌體D1/D2/D3/D4暫對應SW/SE/NE/NW。實測應納入頻率gain與phase，並在相同細胞／液量／光學條件下求M。

# 27組氣流參數掃描



孔徑1.6/2.0/2.4 mm × 孔數4/6/12 × 入口軸距孔板頂面1.5/3/4.5 mm，27組全因子三維CFD，另加無板對照；0.4 mm共同比較網格。改入口高度也改上氣室體積，不能把差異全部歸因於單一距離。

28組皆達宣告的迭代門檻；最大端面質量差0.117%。最低孔板井頭空間平均速度出現在gap_4p5，1 mL/min時0.001316 mm/s；無板0.00080951 mm/s。所有孔板組皆高於無板。這不支持「孔板一定減少細胞所受氣流」。

# CFD方法、影片與適用限制



D3Q19 BGK lattice-Boltzmann，τ=0.8，空氣ρ=1.2 kg/m³、µ=1.8×10^-5 Pa·s。固壁與靜止液面使用no-slip，兩端非平衡外插壓力邊界。實算小密度差0.001、低Re，1 mL/min或0.01 Pa結果以Stokes線性縮放，並非另跑相同工況的非線性解。

每200步檢查，相對速度變化<2×10^-5、端面質量差<0.2%，連續3次才判收斂。0.4→0.3→0.2 mm的基準壓降變化不單調（約-7.8%、+9.1%），局部井速度也變動，因此沒有達到網格獨立。圓管Poiseuille基準、NumPy與C#比對可重現，但不能消除階梯化圓孔誤差。

MP4由儲存速度場推進被動標記；60秒物理時間壓成10秒影片，沿Y投影，近鄰體素取速度，碰固壁停止。不含分子擴散、液內流動、氣味溶解、蒸發、氧傳輸、細胞剪力或生長。故不能據此宣稱細胞不會受傷、氣味已到達受體，或給出接觸時間常數。

# 電子與DLIA數值檢查



原理圖LED1-4 gate接GPIO25/26/27/32，ADC SCLK18、DOUT19、CONVST33。韌體由同一4 kHz硬體時基產生四路整數DDS方波並觸發ADC取樣任務，避免四路LEDC共用timer造成頻率覆寫。2秒窗的I/Q對應8000樣本；ADC等待10 µs，SPI2 MHz。

48組合成測試掃窗長0.5/1/2/4秒、噪聲0.1/1/10 mV與timestamp擾動0/1/10/50 µs。離線joint least-squares最大相對振幅誤差5.82%；此數字不是實板準確率。25%duty DDS在選定頻率的數值頻道洩漏最大約0.71%，仍需量測校正，不宣稱理想正交。

100 MΩ×2.2 pF的簡化回授pole約723 Hz，四頻皆低於此值，但這不是閉迴路穩定度或精度保證。PD電容、板寄生、漏電、100 MΩ元件電壓係數、ADC驅動及Wi-Fi雜訊都應量測。高阻TIA清潔度和guard設計不能由外殼或firmware補救。

# 成本、iGEM證據與發表界線

列印8件耗材估算NT$713.99；核心五金與風扇NT$269.70–452.70；已估光學／氣路NT$140–390。另有濾片、兩個氣體濾器、轉接組及共用設備未報價。PCB報價NT$131,250/2片含設計與開機，平均NT$65,625非量產價。已知單機部分成本NT$66,748.69–67,181.69，不是完整總價。

iGEM Hardware重點包括用途、實際功能與測試、相對既有工具的改善、可重現文件及他人可用性。此套件提供圖、程式、BOM、手冊與問卷；功能驗證和真正使用者回饋仍空白。未找到獨立Overgrad專用數值hardware評分公式，因此不捏造分數或保證獎項。

建議wiki圖組：實物照片與CAD分開標示、LED/PD座標圖、I/J物理定義、參數掃描與SE、CFD對照和網格限制、實測原始曲線、獨立組裝任務統計、成本缺項。把每次需求→計算→實作→測試→迭代連成證據鏈；沒有完成的部分寫planned，不寫validated。

公開前核對圖像與數值來源、第三方datasheet引用／授權、隊伍原始碼授權及個資。文獻方法重現與材料假設要寫在Methods；不把合成示範UI或NN測試的結果當作氣味辨識性能。

# 資料來源與重現資訊

主要幾何／接線來源：使用者提供NTHU_TEST_BOARD_Schematic.pdf、TOP/BOT-0911.pdf、NTHU_TEST_BOARD_BOM.docx。PCB未製造；未取得廠商認證含元件STEP。論文原文與補充資料由使用者paper資料夾讀取。下列資料表／官方頁面用於對照，不代表供應商背書本設計。

Vishay VEMD5060X01 Rev1.2, package drawing and sensitive area
https://www.vishay.com/docs/84278/vemd5060x01.pdf

Wurth155124BS73200, side-view LED
https://www.we-online.com/components/products/datasheet/155124BS73200.pdf

TI ADS8866 RevC, 3-wire CS timing
https://www.ti.com/lit/ds/symlink/ads8866.pdf

TI LMP7721, amplifier design constraints
https://www.ti.com/lit/ds/symlink/lmp7721.pdf

Burton et al., PNAS2020, wireless photometry and supplied supplementary paper
https://pmc.ncbi.nlm.nih.gov/articles/PMC7022161/

iGEM special awards, Hardware
https://competition.igem.org/judging/special-prizes

Espressif LEDC timer sharing
https://docs.espressif.com/projects/esp-idf/en/v4.4.7/esp32/api-reference/peripherals/ledc.html

ATCC HEK293T CRL-3216 cell-line reference
https://www.atcc.org/products/crl-3216

Phrozen resin documentation index
https://helpcenter.phrozen3d.com/hc/en-us/articles/6485205777561-Manuals-and-Documentations

套件含requirements.txt、參數設定、固定種子、原始CSV/NPZ、MC能量帳本、CFD殘差、繪圖與影片程式。manifest.json列每個交付檔案SHA-256。浮點平台差異不要求逐位相同，應比較統計誤差與宣告容差。

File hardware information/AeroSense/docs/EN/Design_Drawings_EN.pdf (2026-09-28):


AeroSense | Engineering prototype | 2026-09-26 | 1

# Assembly and registration drawings

Exploded spacing is illustrative; actual placement is in CAD/assembly_coordinates and parts.json. Nominal overall bounds114 x109 x91 mm exclude hoses/fasteners. Units:mm. Part sheets show views/envelopes, not a complete GD&T manufacturing drawing.

# LED and PD optical registration


PD offset0.4 mm and LED-based well registration are independent. Package orientation, mounting holes and heights still require vendor STEP. Decimal display does not establish +/-0.01 mm accuracy.

# 01_integrated_body

Material:PC_GF_BLACK. Assembly minimum(mm):[-57.0, -52.0, 3.0]. Printable STLs are translated to positive coordinates; do not assemble them by overlapping print origins.

# 02_service_tray

Material:AQUA_8K_GRAY. Assembly minimum(mm):[-57.0, -52.0, -6.0]. Printable STLs are translated to positive coordinates; do not assemble them by overlapping print origins.

# 03_hinged_lid

Material:PC_GF_BLACK. Assembly minimum(mm):[-57.0, -52.0, 76.0]. Printable STLs are translated to positive coordinates; do not assemble them by overlapping print origins.

# 05_well_NE_CLEAR

Material:AQUA_CLEAR_PLUS_TEST_ONLY. Assembly minimum(mm):[0.4, 0.4, 42.5]. Printable STLs are translated to positive coordinates; do not assemble them by overlapping print origins.

# 05_well_NW_CLEAR

Material:AQUA_CLEAR_PLUS_TEST_ONLY. Assembly minimum(mm):[-6.9, 0.4, 42.5]. Printable STLs are translated to positive coordinates; do not assemble them by overlapping print origins.

# 05_well_SW_CLEAR

Material:AQUA_CLEAR_PLUS_TEST_ONLY. Assembly minimum(mm):[-6.9, -5.6, 42.5]. Printable STLs are translated to positive coordinates; do not assemble them by overlapping print origins.

# 05_well_SE_CLEAR

Material:AQUA_CLEAR_PLUS_TEST_ONLY. Assembly minimum(mm):[0.4, -5.6, 42.5]. Printable STLs are translated to positive coordinates; do not assemble them by overlapping print origins.

# 04_common_gas_optical_cap

Material:PC_GF_BLACK. Assembly minimum(mm):[-23.0, -23.0, 56.8]. Printable STLs are translated to positive coordinates; do not assemble them by overlapping print origins.

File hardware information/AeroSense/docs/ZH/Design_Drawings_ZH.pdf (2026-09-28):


AeroSense | Engineering prototype | 2026-09-26 | 1

# 總裝與座標圖

爆炸間距只供說明，實際座標以CAD/assembly_coordinates與parts.json為準。名目外形114×109×91 mm，未 含接管和五金突出。所有圖單位mm，零件圖是視圖與包络尺寸，並非完整GD&T製造圖。

# LED與PD光學對位


PD的0.4 mm偏移與well的LED定位是兩個獨立設定。封裝形狀、板孔與元件高度仍須廠商STEP確認；不要以這 張圖推定精度已達±0.01 mm。

# 01_integrated_body

列印材料：PC_GF_BLACK。組裝座標最小點(mm)：[-57.0, -52.0, 3.0]。STL/檔案已平移至正座標；不能把所有 print STL原點直接重疊組裝。

# 02_service_tray

列印材料：AQUA_8K_GRAY。組裝座標最小點(mm)：[-57.0, -52.0, -6.0]。STL/檔案已平移至正座標；不能把所 有print STL原點直接重疊組裝。

# 03_hinged_lid

列印材料：PC_GF_BLACK。組裝座標最小點(mm)：[-57.0, -52.0, 76.0]。STL/檔案已平移至正座標；不能把所有 print STL原點直接重疊組裝。

# 05_well_NE_CLEAR

列印材料：AQUA_CLEAR_PLUS_TEST_ONLY。組裝座標最小點(mm)：[0.4, 0.4, 42.5]。STL/檔案已平移至正座 標；不能把所有print STL原點直接重疊組裝。

# 05_well_NW_CLEAR

列印材料：AQUA_CLEAR_PLUS_TEST_ONLY。組裝座標最小點(mm)：[-6.9, 0.4, 42.5]。STL/檔案已平移至正座 標；不能把所有print STL原點直接重疊組裝。

# 05_well_SW_CLEAR

列印材料：AQUA_CLEAR_PLUS_TEST_ONLY。組裝座標最小點(mm)：[-6.9, -5.6, 42.5]。STL/檔案已平移至正 座標；不能把所有print STL原點直接重疊組裝。

# 05_well_SE_CLEAR

列印材料：AQUA_CLEAR_PLUS_TEST_ONLY。組裝座標最小點(mm)：[0.4, -5.6, 42.5]。STL/檔案已平移至正座 標；不能把所有print STL原點直接重疊組裝。

# 04_common_gas_optical_cap

列印材料：PC_GF_BLACK。組裝座標最小點(mm)：[-23.0, -23.0, 56.8]。STL/檔案已平移至正座標；不能把所有 print STL原點直接重疊組裝。

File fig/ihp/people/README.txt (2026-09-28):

IHP people portraits
====================
Place consented, project-specific photos here. Do not add stock photos or fabricated faces.

Expected filenames (wired in human-practices.html):

  taoyuan.webp
  farmers.webp
  enose.webp
  challenge-bioproducts.webp
  instrumentation.webp
  fiti.webp
  garageplus.webp
  exporters.webp

Each image is displayed at 88 × 88 px, circle-cropped (object-fit: cover).

Until a file exists, the page shows an initials / organization monogram. Keep that layout; do not invent a face to fill the circle.

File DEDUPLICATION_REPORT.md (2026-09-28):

# Deduplication report

Conservative cleanup only. No page redesign, no invented science, no unique-evidence deletion.

Rule applied: if a concept is fully explained on its owner page, other pages keep **one sentence maximum + a cross-link**.

---

## 1. Individual growers vs institutional buyers

- **Concept:** Individual farmers are not the default buyer; associations / stations / cooperatives / certifiers are.
- **Authoritative page:** `human-practices.html#decision-buyers`
- **Removed from:** `entrepreneurship.html` (learn-card “We heard” retell of farmer resistance and buyer-segment interviews); `sustainability.html` EL-04 interview dump and trace-assoc / trace-analytical “what we heard / what changed” retells.
- **Replacement cross-link:** `human-practices.html#decision-buyers` (Entrepreneurship Who-needs-this lede; Sustainability EL-05).
- **Approximate duplicate text removed:** “Amortized instrument cost is not the prohibitive barrier… Individual farmers resist tools that flag their own product.” / EL-04 bullets on associations, analytical WTP, and buyer-segment correction.
- **Unique evidence kept:** Entrepreneurship buyer/payer role cards, beachhead matrix WTP cells, kill-criteria; Sustainability SDG 10 access consequence and EL-05 “allows us to say.”

---

## 2. Beachhead (six crops → banana)

- **Concept:** FITI/mentor narrowing to Taiwan banana disease-detection as candidate beachhead.
- **Authoritative page:** `human-practices.html#decision-beachhead`
- **Removed from:** `entrepreneurship.html` learn-fiti-bp “We heard” (pain-point / TAM critique); `sustainability.html` EL-04 mentor bullet and trace-mentors TAM rebuild retell.
- **Replacement cross-link:** `human-practices.html#decision-beachhead` · commercial matrix remains `entrepreneurship.html#beachhead`.
- **Approximate duplicate text removed:** “Find the market’s pain point first… instrument-market TAM did not connect to a customer’s loss.” / “rebuild TAM from agricultural VOC opportunity; banana candidate beachhead with mango and tea as follow-ons…”
- **Unique evidence kept:** Entrepreneurship Detectability × Consequence matrix, qualitative labels, kill-criteria, TAM/SAM/SOM consequence in “We changed.”

---

## 3. Screening, not replacement

- **Concept:** AeroSense is an upstream screening layer, not a diagnostic replacement for lab assays.
- **Authoritative page:** `human-practices.html#decision-screening`
- **Removed from:** `entrepreneurship.html` analytical learn-card “We heard”; `sustainability.html` trace-analytical Fast/On-site retell and EL-04 analytical bullet.
- **Replacement cross-link:** `human-practices.html#decision-screening`
- **Approximate duplicate text removed:** “Amortized instrument cost is not the prohibitive barrier described; trained personnel and infrastructure are. Industry is already moving toward smaller mobile labs.”
- **Unique evidence kept:** Entrepreneurship product positioning “Fast · On-site · Low operator dependence” as commercial consequence (`#learn-analytical` We changed; workflow comparison table).

---

## 4. GC-MS comparison

- **Concept:** Do not compete as cheaper GC–MS; labs are confirmatory.
- **Authoritative page:** `human-practices.html#cp-analytical` / `#decision-screening`
- **Removed from:** `entrepreneurship.html` analytical “We heard”; `sustainability.html` EL-04 analytical paragraph.
- **Replacement cross-link:** `human-practices.html#decision-screening`
- **Approximate duplicate text removed:** Full amortized-cost / mobile-lab / “not cheaper GC–MS” paraphrase on Entrepreneurship and Sustainability.
- **Unique evidence kept:** Engineering `xcase-screening` one-line boundary + IHP link; Entrepreneurship workflow table (visual / lab / e-nose / AeroSense) as commercial comparison.

---

## 5. Mold VOC ≠ food safety

- **Concept:** A mold VOC is not a mycotoxin / food-safety verdict (processing can kill fungi while toxin remains).
- **Authoritative page:** `human-practices.html#decision-claims` (Challenge Bioproducts Co., Ltd., 2026-09-12)
- **Removed from:** `entrepreneurship.html#learn-chia` “We heard”; `sustainability.html` EL-04 Challenge bullet; SDG 3↔12 map paraphrase of the aflatoxin warning.
- **Replacement cross-link:** `human-practices.html#decision-claims`
- **Approximate duplicate text removed:** “Start from what the technology can distinguish; mold VOCs do not necessarily represent food safety — processing can kill fungi while toxins such as aflatoxin remain.”
- **Unique evidence kept:** Sustainability EL-15 non-claim (“We do not claim mycotoxin detection”); SDG 3 pathway problem line (one sentence + HP link); Entrepreneurship beachhead matrix cell “Screening ≠ toxin verdict” as a commercial-need label, not a full interview.

---

## 6. Sensing element as bottleneck

- **Concept:** Selectivity / lifetime / reproducibility sit in the sensing element, not electronics/algorithms alone.
- **Authoritative page:** `human-practices.html#decision-sensing`
- **Removed from:** `entrepreneurship.html` e-nose learn-card “We heard”; `sustainability.html` EL-04 CSO bullet and trace-enose competitive-bet retell.
- **Replacement cross-link:** `human-practices.html#decision-sensing`
- **Approximate duplicate text removed:** “Industry priorities: selectivity, sensitivity in real environments, reliability/lifetime, and batch reproducibility. Paraphrase of CSO framing: sensors aren’t good enough yet — hardware and algorithms are the easier part.”
- **Unique evidence kept:** Entrepreneurship “We changed” competitive bet on living OR/Orco + FDM/DLIA readout; Sustainability SDG 9 one-sentence problem + HP link.

---

## 7. Challenge Bioproducts Co., Ltd.

- **Concept:** Dated industry interview that set claim boundary and Detectability × Consequence × Unmet Need × Willingness to Pay.
- **Authoritative page:** `human-practices.html#cp-challenge`
- **Removed from:** Full interview paraphrase on Entrepreneurship and Sustainability EL-04.
- **Replacement cross-link:** `human-practices.html#decision-claims`
- **Approximate duplicate text removed:** Same aflatoxin / processing / “start from what the technology can distinguish” block (see §5).
- **Unique evidence kept:** Entrepreneurship beachhead **framework attribution** (the 4-factor matrix is a commercial tool); dated learn-card header; Sustainability trace-biotech header/date.

---

## 8. Fast / On-site / Low operator dependence

- **Concept:** Positioning triad from the analytical-instrumentation interview.
- **Authoritative page:** `human-practices.html#decision-screening`
- **Removed from:** Sustainability trace-analytical “what changed” (full triad + buyer dump); Entrepreneurship intro caption retell of the interview.
- **Replacement cross-link:** `human-practices.html#decision-screening`
- **Approximate duplicate text removed:** “Positioning became Fast · On-site · Low operator dependence as an upstream screening layer. Buyer segment corrected toward associations, stations, cooperatives, and certifiers.” (Sustainability trace)
- **Unique evidence kept:** Entrepreneurship `#learn-analytical` **We changed** (commercial consequence) and product-system use of the triad.

---

## 9. OR / Orco mechanism

- **Concept:** Insect ORs are not GPCRs; OR–Orco is a heteromeric ligand-gated ion channel; HEK293 assay architecture.
- **Authoritative page:** `design.html#how-aerosense-senses`
- **Removed from:** `hardware.html` opening / “Why hardware?” mechanism paragraphs (citations kept via remaining source line); `js/notebook-data.js` wet-ideation `work` essay.
- **Replacement cross-link:** `design.html#how-aerosense-senses`
- **Approximate duplicate text removed:** Hardware: “Receptor activation is intended to raise intracellular Ca²⁺, and GCaMP reports that rise as fluorescence [Zboray/Chen].” Notebook: “building HEK293 cell lines that co-express a Drosophila melanogaster odorant receptor (OR) with the universal co-receptor Orco fused to a calcium indicator.”
- **Unique evidence kept:** Design Module 2 / topology; Parts one-line roles; Engineering Wet Lab cycles only where needed to understand IRES→fusion iteration; Contribution lesson one-liner + Engineering links.

---

## 10. GCaMP topology (current vs old)

- **Concept:** Current N-terminal GCaMP6f–(GGGGS)₃–DmOrco rationale vs IRES-downstream failure.
- **Authoritative page (current):** `design.html#topology`
- **Authoritative page (old / redesign):** `engineering.html#wl-cycle-1` / `#wl-cycle-2`
- **Removed from:** Notebook mechanism/WHY (already pointed at Design/Engineering); no further GCaMP essay cut on Engineering (iteration-owned).
- **Replacement cross-link:** Design for current rationale; Engineering for Cycle 1–2 history.
- **Approximate duplicate text removed:** Notebook ideation mechanism (see §9). Fusion redesign `work` already chronology-only.
- **Unique evidence kept:** Engineering cycle evidence (weak VUAA1 observation, fusion redesign maps); Parts topology pointer; Contribution reuse lesson.

---

## 11. Shared codon-optimisation sentence (9-receptor DOM)

- **Concept:** “All nine ORFs are codon-optimised for human expression (CTG constitutes ~92% of leucine codons; GC3 ≈ 0.83).”
- **Authoritative location:** `design.html` · Receptor panel and codon optimisation (once, with Roberts citation).
- **Removed from:** Nine `#spec-or-Or*` articles (each copied panel-role + codon + no-ligand sentences). Also removed the same codon sentence from `#spec-m1-or` inspector copy.
- **Replacement cross-link:** Collection intro under `#design-or-catalog` + `#receptor-panel`; per-receptor nodes keep only the Zboray-overlap distinction.
- **Approximate duplicate text removed:** Nine copies of panel-role / codon-opt / no-ligand paragraphs; seven copies of “remaining seven are new…”; two copies of the Or85b/Or98a overlap sentence inside receptor nodes.
- **Unique evidence kept:** Or85b / Or98a “Overlaps the Zboray et al. platform.” vs others “Not listed as overlapping…”

---

## 12. Hardware V1 vs V2 ownership

- **Concept:** V1 redesign history vs current V2 architecture.
- **Authoritative pages:** V1 = `engineering.html#track-hardware`; V2 architecture = `hardware.html`
- **Removed from:** None additional. Hardware `#v1-archive` was already archive + Engineering link only.
- **Replacement cross-link:** `hardware.html#v1-archive` → `engineering.html#track-hardware`
- **Approximate duplicate text removed:** — (already compliant)
- **Unique evidence kept:** Engineering DRC/ERC counts, iST review, Pi-removal cycle; Hardware V2 BOM, schematic, explorer, validation ladder.

---

## 13. Model pipeline vs failed approaches

- **Concept:** Current Decode pipeline vs Dry Lab Cycle 0–1 failures (single-seed luck, missing StandardScaler, invalidated quantization).
- **Authoritative page (current):** `model.html` pipeline / evidence A.
- **Authoritative page (failed / invalidated):** `engineering.html#track-drylab`
- **Removed from:** `model.html` “What Did the Model Teach Us?” evidence blocks that retold Cycle 0–1 history (S13 vs S6 ranking, Brian2 clock-scheduling narrative).
- **Replacement cross-link:** `engineering.html#track-drylab`
- **Approximate duplicate text removed:** “sensor-importance rankings tracked raw magnitude (e.g. S13 vs S6) rather than clean separability, disagreeing with standardized SVM / ANOVA-F diagnostics.” / “found `quantize_states` was scheduled on the wrong Brian2 clock — prior bit-sweep conclusions are invalidated pending rerun.”
- **Unique evidence kept:** Model design consequences (keep v0 preset; do not promote on one seed; hold hardware bit-depth until rerun).

---

## 14. Notebook chronology vs Engineering essays

- **Concept:** Notebook must not become a second Engineering page.
- **Authoritative page:** `notebook.html` / `js/notebook-data.js` for dates and outcomes; `engineering.html` for DBTL rationale.
- **Removed from:** `js/notebook-data.js` `wet-ideation.work` mechanism essay.
- **Replacement cross-link:** `design.html` (mechanism/topology); Engineering for cycle WHY.
- **Approximate duplicate text removed:** Multi-sentence OR+Orco+GCaMP fusion definition in April ideation `work`.
- **Unique evidence kept:** Cycle 0 vector-rescue observation (no mammalian promoter/polyA) — documents what happened, not a second mechanism page. Fusion redesign `work` already chronology + Design/Engineering links.

---

## 15. Desktop / mobile prose copies

- **Concept:** Separate mobile HTML repeating table facts.
- **Authoritative DOM:** Entrepreneurship `.ent-matrix` tables (beachhead, workflow, capability).
- **Removed from:** `entrepreneurship.html` three `.ent-matrix-mobile` blocks.
- **Replacement:** Same table DOM restyled at `max-width: 899px` in `css/entrepreneurship.css` (`data-label` / column `nth-child` captions).
- **Approximate duplicate text removed:** Six beachhead candidate cards; four workflow cards (Visual / lab / e-nose / AeroSense); three capability regrouping cards.
- **Unique evidence kept:** Full matrix cell source notes (mobile cards had dropped them).

---

## Inspected, already compliant (no cut)

| Location | Why left |
| --- | --- |
| `engineering.html` HP cards `xcase-*` | Already one sentence + IHP link |
| `hardware.html#v1-archive` | Archive files + Engineering link only |
| `parts.html` catalog | Collection-level codon note; per-row role is one line |
| `contribution.html` IRES lesson | One-line observation + Engineering links |
| `description.html` OR–Orco line | Whole-project story; one sentence, not a second Design page |
| Sustainability SDG pathway **consequences** | SDG 2.3/10 access tension, EL-15 non-claim, EL-09 hypothesis — unique to this page |

---

## Files touched

- `aerosense-wiki/design.html`
- `aerosense-wiki/entrepreneurship.html`
- `aerosense-wiki/css/entrepreneurship.css`
- `aerosense-wiki/sustainability.html`
- `aerosense-wiki/hardware.html`
- `aerosense-wiki/model.html`
- `aerosense-wiki/engineering.html`
- `aerosense-wiki/js/notebook-data.js`
- `aerosense-wiki/DEDUPLICATION_REPORT.md` (this file)

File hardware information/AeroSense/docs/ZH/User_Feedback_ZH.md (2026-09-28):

# 使用者回饋：參與者資料

目的為改善組裝、操作和說明書。自願參與，可隨時停止或略過題目；本表不收姓名、學號或聯絡方式。照片、錄影或公開引用需另取得同意。依學校規定確認此活動所需的人類參與研究程序。

| 欄位 | 填答 |
| 匿名代碼／日期 | ________________________ |
| 手冊語言／檔案雜湊 | ZH / EN；________________ |
| 背景 | 生科／電機／機械／其他________ |
| 3D列印組裝經驗 | 無／1-3件／4件以上 |
| 先前是否接觸AeroSense | 無／閱讀過／組裝過 |
| 所用板件 | 紙板模板／實板；________________ |
| 試驗同意 | 了解可隨時停止：是／否 |

測試只用乾式零件、假井／無細胞樣品，不接壓力氣體。電子與UI部分用明確標示的示範模式，除非另有經確認的實板流程。觀察員不主動教學，求助時才回應並記錄；不要求硬壓或冒險。

# 任務記錄與評分

| 任務 | 秒／完成／求助次數／錯誤 |
| 依BOM找齊材料與零件 | ________________________ |
| 依圖裝風扇、PCB、外殼 | ________________________ |
| 辨認井別並裝內蓋／氣管 | ________________________ |
| 開蓋、取換井並再次關閉 | ________________________ |
| UI連線、開始、停止 | ________________________ |
| 辨認DEMO與invalid；匯出 | ________________________ |

評分：1非常不同意、2不同意、3中立、4同意、5非常同意，或N/A。每题独立作答；以下為本專案自訂題，不是經驗證SUS量表，不換算成SUS分數。

| 題目 | 1 2 3 4 5 N/A |
| 我能分辨每個零件與其方向 | ________________ |
| 步驟和圖片足以讓我操作 | ________________ |
| 螺絲／工具容易取得與使用 | ________________ |
| 換井不需過度施力 | ________________ |
| 開關蓋不會拉扯管線或碰到井 | ________________ |
| 我能辨認进氣與排氣 | ________________ |
| UI狀態及錯誤容易理解 | ________________ |
| 我能分清模擬和實機資料 | ________________ |
| 我願意依此文件再次組裝 | ________________ |

# 開放回饋與分析方法

最不清楚的步驟／圖號：________________________________________________
最難裝或最容易裝錯的零件：____________________________________________
哪個零件或採購項目可以取消？原因：____________________________________
哪個操作使你擔心碰件、漏液或弄髒？____________________________________
最希望先改的一件事：__________________________________________________
其他意見：__________________________________________________________

觀察員另記：零件破損、錯方向、未壓到底、漏裝墊片、螺絲過緊、軟管拉扯、求助內容與時間。完成定義須事前固定：零件齊全、方向正確、井可取換、連接器可使用、無可見受力，不可只以「看起來組好了」判定。

分析：報參與人數與背景、任務完成率、時間中位數／IQR、求助和錯誤種類。Likert逐題報分布，不只報平均；N/A不算中立。先以5位新手做形成性試驗，不以此宣稱普遍可用性；改善後邀新參與者重測，避免只量到學習效應。

wiki呈現用可追溯的回饋→設計決策→新測試結果表。保留負面回饋，不捏造滿意度、使用者數或問卷結果。參與者引述匿名化後再公開。

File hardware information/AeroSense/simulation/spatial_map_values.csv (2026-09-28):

radial_r_mm | z_above_PCB_mm | eta | eta_SE | detected_packets | Phi_ex_uW_mm2 | Phi_em_uW_mm2 | Phi_em_SE | J_uW_mm2 | J_SE_first_order
2.0 | 3.75 | 0.010427387553113756 | 0.00052512003593092 | 855 | 1.7716480132859553 | 0.03425625629482363 | 0.0009132668271511538 | 0.0003572032605049187 | 2.035383719096584e-05
2.0 | 4.25 | 0.007385855671035577 | 0.00044354310983194125 | 656 | 3.248947344920895 | 0.024728150390900674 | 0.0004566288484740238 | 0.00018263854979885436 | 1.1474817444370857e-05
2.0 | 4.75 | 0.004757117477895038 | 0.0003568813047501619 | 432 | 3.3384174914885336 | 0.020771916848437346 | 0.001213330373061123 | 9.881444868908371e-05 | 9.395192805024015e-06
2.0 | 5.25 | 0.002797996651065432 | 0.0002729256731988211 | 383 | 4.519499030193793 | 0.016935813509624243 | 0.00028329995870969544 | 4.7386349482997334e-05 | 4.6896941771317176e-06
2.0 | 5.75 | 0.0030495308270605155 | 0.0002851233504070099 | 327 | 6.038315125683134 | 0.016729510331001268 | 0.0003527779454079413 | 5.101715747601574e-05 | 4.889786649767518e-06
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

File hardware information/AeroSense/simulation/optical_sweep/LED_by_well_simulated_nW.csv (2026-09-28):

NE | NW | SW | SE
6.599620936503317603e-01 | 1.684632361162457220e-06 | 0.000000000000000000e+00 | 1.789884294599952685e-02
1.484856072388596356e-02 | 7.396003197839632337e-01 | 9.953063874488850152e-05 | 0.000000000000000000e+00
0.000000000000000000e+00 | 5.043132139580827449e-03 | 7.928579097177723689e-01 | 1.500695528592856098e-02
3.262704759849973518e-02 | 0.000000000000000000e+00 | 5.404251946377970454e-03 | 8.812700144924675572e-01

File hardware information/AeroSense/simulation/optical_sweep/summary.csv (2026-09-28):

case | green_mean_nW | green_SE_nW | blue_mean_nW | blue_SE_nW | replicates | packets_per_rep | NE_green_nW | NW_green_nW | SW_green_nW | SE_green_nW
baseline | 0.6778626212286923 | 0.09215867148434073 | 0.00018418889517750252 | 4.174415687875561e-05 | 3 | 56000 | 0.6599620936503318 | 1.6846323611624572e-06 | 0.0 | 0.017898842945999527
PD_centered | 0.8976477626989926 | 0.04871320748795129 | 0.00018243343297822786 | 2.3736818979352706e-05 | 3 | 56000 | 0.8754184565692847 | 1.727926854657142e-06 | 0.0 | 0.022227578202853242
PD_reversed | 1.0678601527190896 | 0.06889647877591733 | 0.00023598657949654966 | 3.813199984554283e-05 | 3 | 56000 | 1.04517718562784 | 0.0 | 0.0 | 0.02268296709124967
PD_x_minus | 0.6889551715952505 | 0.023250636332841915 | 0.00019368919675836314 | 8.26263175142662e-05 | 3 | 56000 | 0.6558619958943862 | 6.4454792317996e-10 | 0.0 | 0.03309317505631653
PD_x_plus | 0.6539185321955336 | 0.009333721411031391 | 0.0001247050042131605 | 3.021893530809784e-05 | 3 | 56000 | 0.6417521192668583 | 0.0 | 0.0 | 0.012166412928675319
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

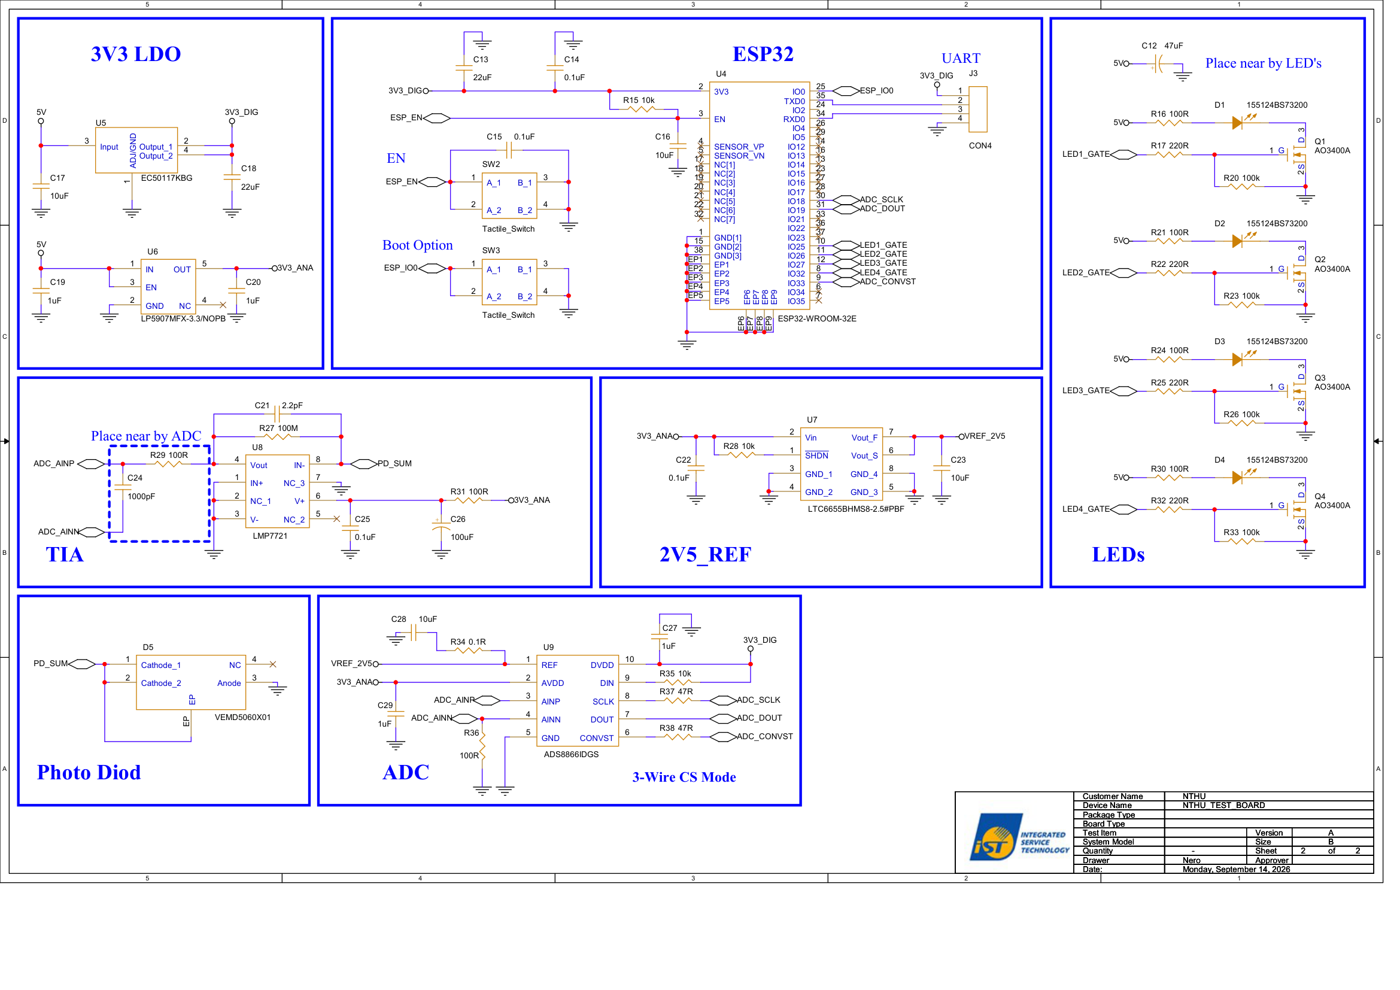
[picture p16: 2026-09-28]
fig/hardware/schematics/v2-schematic-p2.png

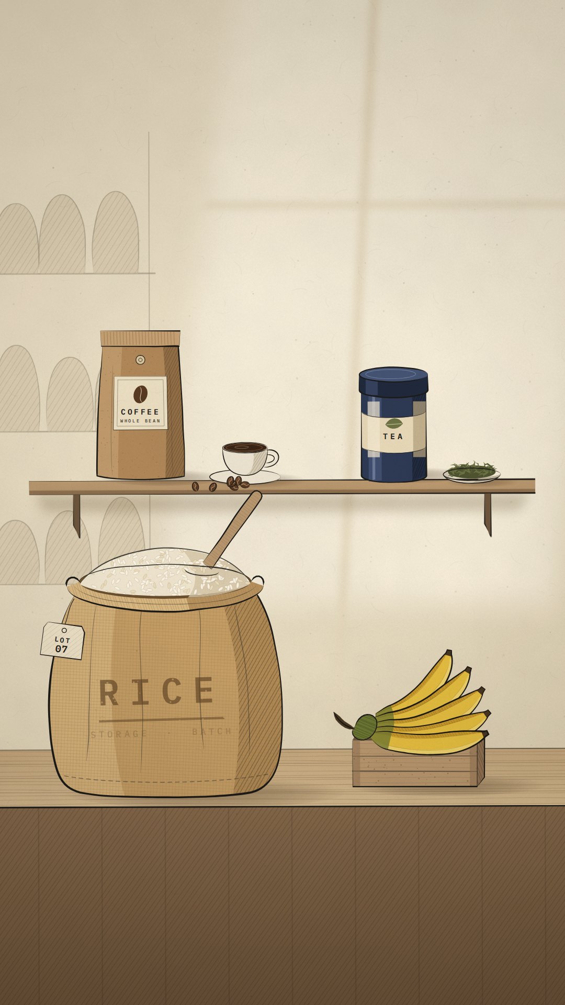
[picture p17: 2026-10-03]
homepage_animation/media/posters/portrait-poster-normal.jpg

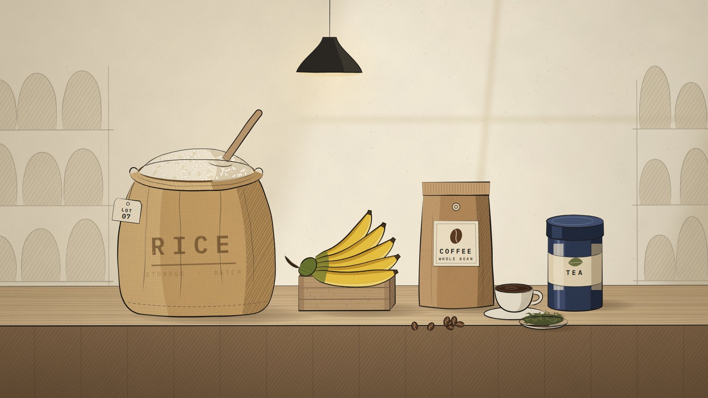
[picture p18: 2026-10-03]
homepage_animation/media/posters/landscape-s1-normal.jpg

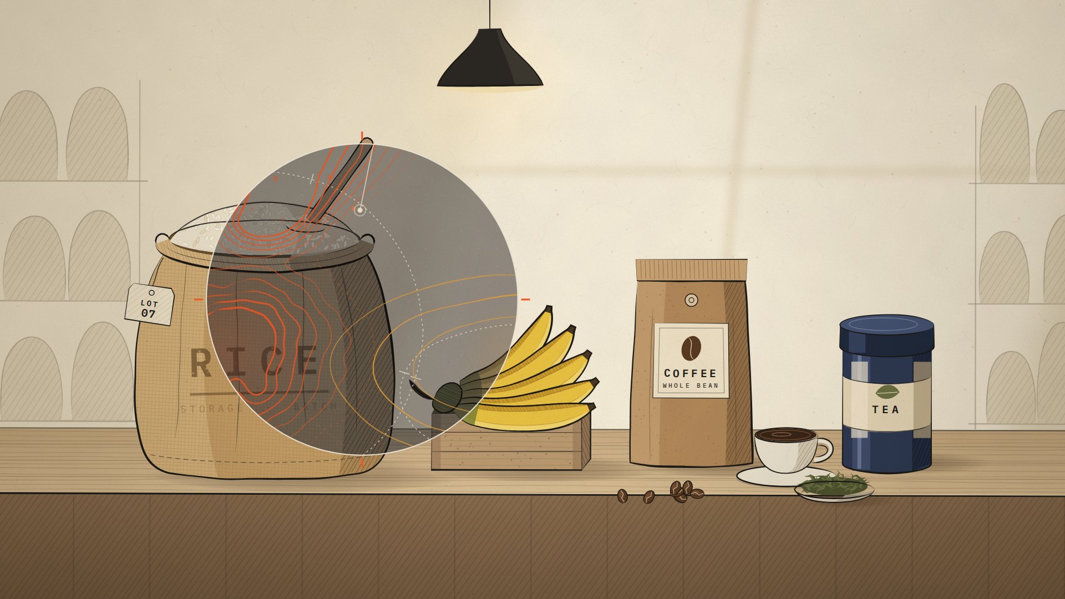
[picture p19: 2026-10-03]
homepage_animation/media/posters/landscape-s2-lens.jpg

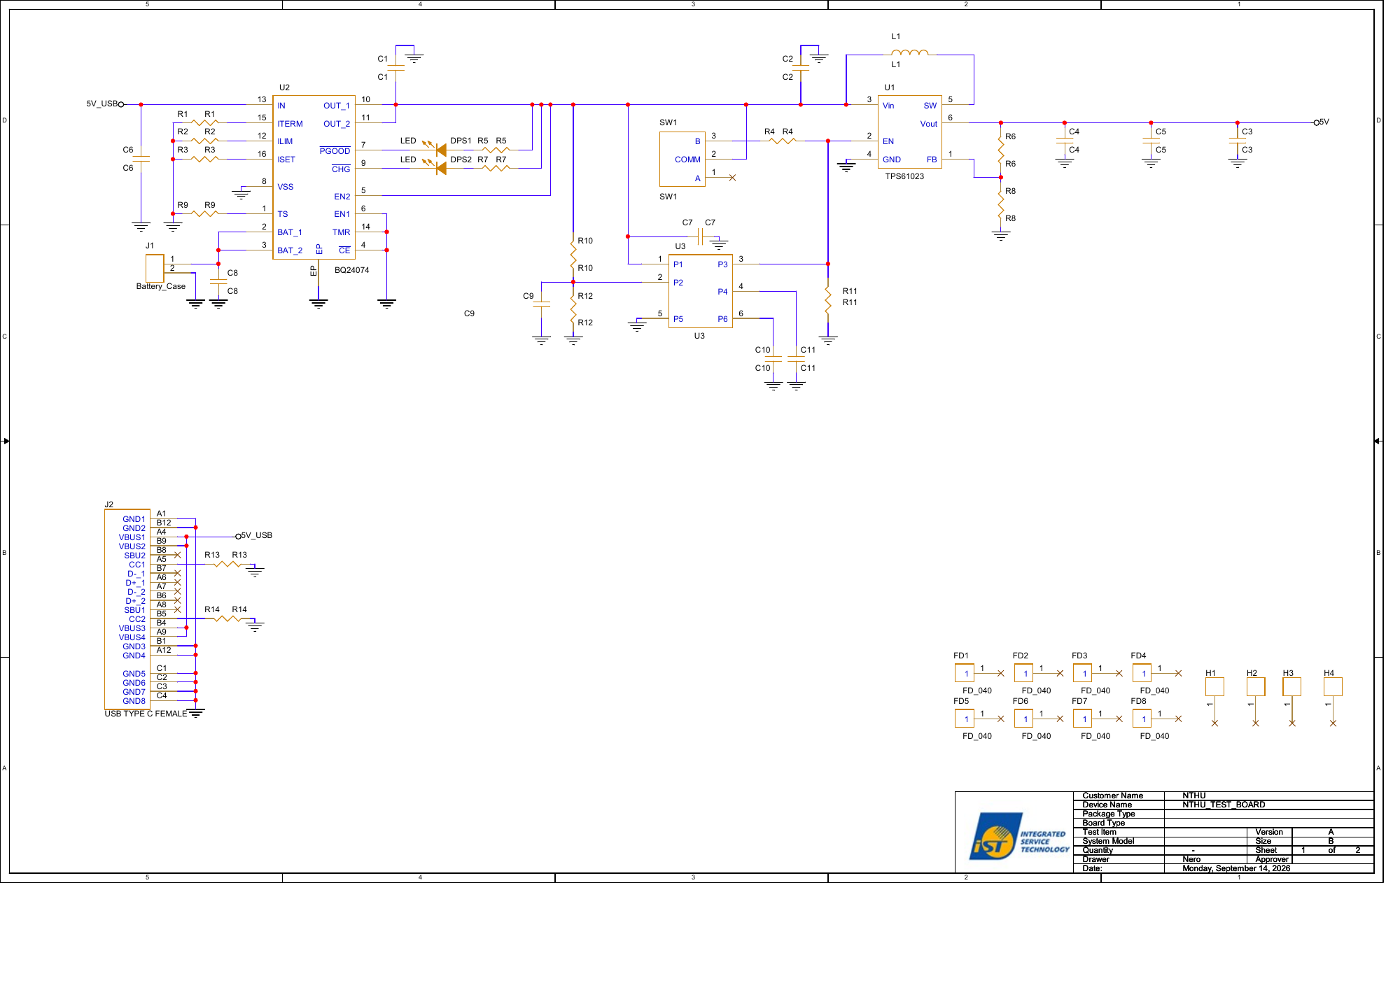
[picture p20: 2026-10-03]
fig/hardware/schematics/reader-schematic-1.png

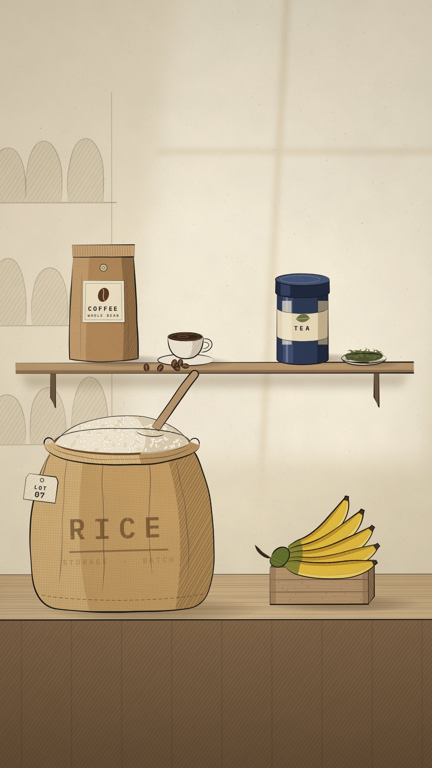
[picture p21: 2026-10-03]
homepage_animation/media/posters/portrait-s1-normal.jpg

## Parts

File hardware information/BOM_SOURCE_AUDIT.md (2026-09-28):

# BOM source audit

Internal. Not a public release file.

Source: `hardware information/pcb v2/NTHU_TEST_BOARD_BOM.docx`
Compared against: current schematic (`NTHU_TEST_BOARD_Schematic.pdf`) and the team design report (English hardware content + Fluorescence Detection Hardware Module Design Report).

**Do not invent component values.** Blank cells stay blank.

## Verdict

**Not release-ready.** Do not publish this DOCX as the final BOM. Do not write `hardware information/release/AeroSense_Reader_BOM.csv` until every required field is filled from a verified schematic/orderable part list.

Header column 4 is Chinese (`零件參數` = part parameter / value). The file also contains internal fabrication annotations.

## Header

| Col | Raw |
| --- | --- |
| 1 | `Item` |
| 2 | `Quantity` |
| 3 | `Reference` |
| 4 | `零件參數` ← Chinese; treat as Value |

## Row-by-row

| Item | Qty | Reference | Value (零件參數) | Flags |
| --- | --- | --- | --- | --- |
| 1 | 1 | `C1` | *(blank)* | blank value; missing manufacturer; missing MPN; missing package / footprint |
| 2 | 1 | `C2` | *(blank)* | blank value; missing manufacturer; missing MPN; missing package / footprint |
| 3 | 1 | `C3` | *(blank)* | blank value; missing manufacturer; missing MPN; missing package / footprint |
| 4 | 1 | `C4` | *(blank)* | blank value; missing manufacturer; missing MPN; missing package / footprint |
| 5 | 1 | `C5` | *(blank)* | blank value; missing manufacturer; missing MPN; missing package / footprint |
| 6 | 1 | `C6` | *(blank)* | blank value; missing manufacturer; missing MPN; missing package / footprint |
| 7 | 1 | `C7` | *(blank)* | blank value; missing manufacturer; missing MPN; missing package / footprint |
| 8 | 1 | `C8` | *(blank)* | blank value; missing manufacturer; missing MPN; missing package / footprint |
| 9 | 1 | `C9` | *(blank)* | blank value; missing manufacturer; missing MPN; missing package / footprint |
| 10 | 1 | `C10` | *(blank)* | blank value; missing manufacturer; missing MPN; missing package / footprint |
| 11 | 1 | `C11` | *(blank)* | blank value; missing manufacturer; missing MPN; missing package / footprint |
| 12 | 1 | `C12` | 47uF | missing manufacturer; missing MPN; missing package / footprint |
| 13 | 2 | `C13,C18` | 22uF | missing manufacturer; missing MPN; missing package / footprint |
| 14 | 4 | `C14,C15,C22,C25` | 0.1uF | missing manufacturer; missing MPN; missing package / footprint |
| 15 | 4 | `C16,C17,C23,C28` | 10uF | missing manufacturer; missing MPN; missing package / footprint |
| 16 | 4 | `C19,C20,C27,C29` | 1uF | missing manufacturer; missing MPN; missing package / footprint |
| 17 | 1 | `C21` | 2.2pF | missing manufacturer; missing MPN; missing package / footprint |
| 18 | 1 | `C24` | 1000pF | missing manufacturer; missing MPN; missing package / footprint |
| 19 | 1 | `C26` | 100uF | missing manufacturer; missing MPN; missing package / footprint |
| 20 | 2 | `DPS1,DPS2` | LED | generic name; missing manufacturer; missing MPN; missing package / footprint |
| 21 | 4 | `D1,D2,D3,D4` | 155124BS73200 | missing manufacturer; missing MPN; missing package / footprint |
| 22 | 1 | `D5` | VEMD5060X01 | missing manufacturer; missing MPN; missing package / footprint |
| 23 | 8 | `FD1,FD2,FD3,FD4,FD5,FD6,FD7,FD8` | FD_040(SMT用光學點) | Chinese characters; generic name; missing manufacturer; missing MPN; missing package / footprint |
| 24 | 4 | `H1,H2,H3,H4` | CON(銅柱孔) | Chinese characters; generic name; missing manufacturer; missing MPN; missing package / footprint |
| 25 | 1 | `J1` | Battery_Case | generic name; missing manufacturer; missing MPN; missing package / footprint |
| 26 | 1 | `J2` | USB TYPE C FEMALE | generic name; missing manufacturer; missing MPN; missing package / footprint |
| 27 | 1 | `J3` | CON4(4pin排針) | Chinese characters; generic name; missing manufacturer; missing MPN; missing package / footprint |
| 28 | 1 | `L1` | *(blank)* | blank value; missing manufacturer; missing MPN; missing package / footprint |
| 29 | 4 | `Q1,Q2,Q3,Q4` | AO3400A | missing manufacturer; missing MPN; missing package / footprint |
| 30 | 1 | `R1` | *(blank)* | blank value; missing manufacturer; missing MPN; missing package / footprint |
| 31 | 1 | `R2` | *(blank)* | blank value; missing manufacturer; missing MPN; missing package / footprint |
| 32 | 1 | `R3` | *(blank)* | blank value; missing manufacturer; missing MPN; missing package / footprint |
| 33 | 1 | `R4` | *(blank)* | blank value; missing manufacturer; missing MPN; missing package / footprint |
| 34 | 1 | `R5` | *(blank)* | blank value; missing manufacturer; missing MPN; missing package / footprint |
| 35 | 1 | `R6` | *(blank)* | blank value; missing manufacturer; missing MPN; missing package / footprint |
| 36 | 1 | `R7` | *(blank)* | blank value; missing manufacturer; missing MPN; missing package / footprint |
| 37 | 1 | `R8` | *(blank)* | blank value; missing manufacturer; missing MPN; missing package / footprint |
| 38 | 1 | `R9` | *(blank)* | blank value; missing manufacturer; missing MPN; missing package / footprint |
| 39 | 1 | `R10` | *(blank)* | blank value; missing manufacturer; missing MPN; missing package / footprint |
| 40 | 1 | `R11` | *(blank)* | blank value; missing manufacturer; missing MPN; missing package / footprint |
| 41 | 1 | `R12` | *(blank)* | blank value; missing manufacturer; missing MPN; missing package / footprint |
| 42 | 1 | `R13` | *(blank)* | blank value; missing manufacturer; missing MPN; missing package / footprint |
| 43 | 1 | `R14` | *(blank)* | blank value; missing manufacturer; missing MPN; missing package / footprint |
| 44 | 3 | `R15,R28,R35` | 10k | missing manufacturer; missing MPN; missing package / footprint |
| 45 | 7 | `R16,R21,R24,R29,R30,R31,R36` | 100R | missing manufacturer; missing MPN; missing package / footprint |
| 46 | 4 | `R17,R22,R25,R32` | 220R | missing manufacturer; missing MPN; missing package / footprint |
| 47 | 4 | `R20,R23,R26,R33` | 100k | missing manufacturer; missing MPN; missing package / footprint |
| 48 | 1 | `R27` | 100M | missing manufacturer; missing MPN; missing package / footprint |
| 49 | 1 | `R34` | 0.1R | missing manufacturer; missing MPN; missing package / footprint |
| 50 | 2 | `R37,R38` | 47R | missing manufacturer; missing MPN; missing package / footprint |
| 51 | 1 | `SW1` | SW1 | generic name; missing manufacturer; missing MPN; missing package / footprint |
| 52 | 2 | `SW2,SW3` | Tactile_Switch | generic name; missing manufacturer; missing MPN; missing package / footprint |
| 53 | 1 | `U1` | TPS61023 | missing manufacturer; missing MPN; missing package / footprint |
| 54 | 1 | `U2` | BQ24074 | missing manufacturer; missing MPN; missing package / footprint |
| 55 | 1 | `U3` | *(blank)* | blank value; missing manufacturer; missing MPN; missing package / footprint |
| 56 | 1 | `U4` | ESP32-WROOM-32E | missing manufacturer; missing MPN; missing package / footprint |
| 57 | 1 | `U5` | EC50117KBG | missing manufacturer; missing MPN; missing package / footprint |
| 58 | 1 | `U6` | LP5907MFX-3.3/NOPB | missing manufacturer; missing MPN; missing package / footprint |
| 59 | 1 | `U7` | LTC6655BHMS8-2.5#PBF | missing manufacturer; missing MPN; missing package / footprint |
| 60 | 1 | `U8` | LMP7721 | missing manufacturer; missing MPN; missing package / footprint |
| 61 | 1 | `U9` | ADS8866IDGS | missing manufacturer; missing MPN; missing package / footprint |

## Known problems (do not fill by guessing)

### Blank values

- Capacitors **C1–C11**: value blank.
- Inductor **L1**: value blank.
- Resistors **R1–R14**: value blank.
- IC **U3**: value blank.

Expanded blank-value references: `C1`, `C2`, `C3`, `C4`, `C5`, `C6`, `C7`, `C8`, `C9`, `C10`, `C11`, `L1`, `R1`, `R2`, `R3`, `R4`, `R5`, `R6`, `R7`, `R8`, `R9`, `R10`, `R11`, `R12`, `R13`, `R14`, `U3`.

### Chinese internal annotations

- Header: `零件參數`.
- `FD1,FD2,FD3,FD4,FD5,FD6,FD7,FD8 = FD_040(SMT用光學點)`
- `H1,H2,H3,H4 = CON(銅柱孔)`
- `J3 = CON4(4pin排針)`

Decoded (source strings, not replacements):
- `SMT用光學點` — SMT optical fiducial.
- `銅柱孔` — copper-standoff / pillar hole.
- `4pin排針` — 4-pin header.

These must be rewritten in English *from a verified mechanical drawing*, not guessed into MPNs.

### Generic names (not orderable)

- `DPS1,DPS2 = LED`
- `FD1,FD2,FD3,FD4,FD5,FD6,FD7,FD8 = FD_040(SMT用光學點)`
- `H1,H2,H3,H4 = CON(銅柱孔)`
- `J1 = Battery_Case`
- `J2 = USB TYPE C FEMALE`
- `J3 = CON4(4pin排針)`
- `SW1 = SW1`
- `SW2,SW3 = Tactile_Switch`
- `SW1` as both reference and value.

### Missing MPN / manufacturer / footprint

Every DOCX row lacks manufacturer, manufacturer part number, and package/footprint columns. Even rows that list a catalog-like value (e.g. `155124BS73200`, `ADS8866IDGS`) are **not** a complete release line until manufacturer + orderable MPN + footprint are verified against the current schematic.

### Schematic / design-report disagreements (do not silently reconcile)

- Design study (hardware design report): first-design recommended feedback capacitor **4.7 pF** with **100 MΩ** → ~339 Hz simple RC pole.
- Current schematic / this BOM: **C21 = 2.2 pF** and **R27 = 100 M**. That is a different network (~723 Hz simple RC pole). **Do not replace one with the other.**
- Retired V1 BOM listed TIA *C<sub>F</sub>* as **C1 = 2.2 pF**. This DOCX leaves **C1 blank** and puts **2.2 pF on C21**. Reference mapping is unverified — do not copy V1 values onto C1–C11.
- Retired V1 BOM listed TIA *R<sub>F</sub>* as **R13 = 100 M** with an HVC1206-series note. This DOCX leaves **R13 blank** and lists **R27 = 100 M**. Do not assume R13 is still 100 MΩ.
- **R16, R21, R24, R29, R30, R31, R36 = 100R** (seven resistors). The design report selects **100 Ω per LED** as a conservative prototype start. This file does not state which of those 100 Ω parts are LED series resistors. Do not assign them.
- **R37, R38 = 47R** is consistent with the documented 47 Ω SCLK/CONVST damping, but the DOCX does not name that function.
- **C24 = 1000 pF** is numerically 1 nF; the design report uses a 100 Ω + 1 nF ADC input network. Not confirmed as the same part.
- Photodiode **D5 = VEMD5060X01** and LEDs **D1–D4 = 155124BS73200** match the design report identities; package/MPN still missing.
- **U8 = LMP7721**, **U9 = ADS8866IDGS**, **U7 = LTC6655BHMS8-2.5#PBF** match the design-report devices; manufacturer/footprint still missing.

### Duplicate references

No duplicate reference designators after expanding grouped cells (e.g. `C13,C18`).

## Release gate

`scripts/check_hardware_bom.py` must pass on `hardware information/release/AeroSense_Reader_BOM.csv` before that CSV is linked as the public BOM.

Required CSV columns: Reference, Quantity, Value, Manufacturer, Manufacturer Part Number, Package / footprint, Function, Notes.

Until then: interactive wiki table may show this draft with **Not frozen in source BOM** for empty fields. It must not be labeled final.

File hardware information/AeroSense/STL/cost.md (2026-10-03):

\*\*phrozen sonic mighty revo 16k

01\_integrated\_body\*\*

material: PC-GF like, black

estimated printing time: 21hr 13min

resin volume: 210.436 mL

resin weight: 231.479 g

resin price: 509.255 NTD

02+03+04

material: PC-GF like, black

estimated printing time: 17hr 19min

resin volume: 152.39 mL

resin weight: 167.629 g

resin price: 368.784 NTD

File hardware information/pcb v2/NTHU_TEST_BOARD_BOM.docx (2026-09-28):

NTHU_TEST_BOARD BOM

Item | Quantity | Reference | 零件參數
1 | 1 | C1
2 | 1 | C2
3 | 1 | C3
4 | 1 | C4
5 | 1 | C5
6 | 1 | C6
7 | 1 | C7
8 | 1 | C8
9 | 1 | C9
10 | 1 | C10
11 | 1 | C11
12 | 1 | C12 | 47uF
13 | 2 | C13,C18 | 22uF
14 | 4 | C14,C15,C22,C25 | 0.1uF
15 | 4 | C16,C17,C23,C28 | 10uF
16 | 4 | C19,C20,C27,C29 | 1uF
17 | 1 | C21 | 2.2pF
18 | 1 | C24 | 1000pF
19 | 1 | C26 | 100uF
20 | 2 | DPS1,DPS2 | LED
21 | 4 | D1,D2,D3,D4 | 155124BS73200
22 | 1 | D5 | VEMD5060X01
23 | 8 | FD1,FD2,FD3,FD4,FD5,FD6,FD7,FD8 | FD_040(SMT用光學點)
24 | 4 | H1,H2,H3,H4 | CON(銅柱孔)
25 | 1 | J1 | Battery_Case
26 | 1 | J2 | USB TYPE C FEMALE
27 | 1 | J3 | CON4(4pin排針)
28 | 1 | L1
29 | 4 | Q1,Q2,Q3,Q4 | AO3400A
30 | 1 | R1
31 | 1 | R2
32 | 1 | R3
33 | 1 | R4
34 | 1 | R5
35 | 1 | R6
36 | 1 | R7
37 | 1 | R8
38 | 1 | R9
39 | 1 | R10
40 | 1 | R11
41 | 1 | R12
42 | 1 | R13
43 | 1 | R14
44 | 3 | R15,R28,R35 | 10k
45 | 7 | R16,R21,R24,R29,R30,R31,R36 | 100R
46 | 4 | R17,R22,R25,R32 | 220R
47 | 4 | R20,R23,R26,R33 | 100k
48 | 1 | R27 | 100M
49 | 1 | R34 | 0.1R
50 | 2 | R37,R38 | 47R
51 | 1 | SW1 | SW1
52 | 2 | SW2,SW3 | Tactile_Switch
53 | 1 | U1 | TPS61023
54 | 1 | U2 | BQ24074
55 | 1 | U3
56 | 1 | U4 | ESP32-WROOM-32E
57 | 1 | U5 | EC50117KBG
58 | 1 | U6 | LP5907MFX-3.3/NOPB
59 | 1 | U7 | LTC6655BHMS8-2.5#PBF
60 | 1 | U8 | LMP7721
61 | 1 | U9 | ADS8866IDGS

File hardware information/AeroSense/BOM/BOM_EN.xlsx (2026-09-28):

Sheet: Summary
AeroSense material cost
Item | Low TWD | High TWD | Editable assumptions | Value
Two-PCB quote incl. design/setup | 131250.00 | 131250.00 | Board count | 2
Average board in this quote | 65625.00 | 65625.00 | Resin density g/cm3 | 1.1
Eight printed parts, consumed resin | 713.99 | 713.99 | Support/waste factor | 1.35
Core hardware and fan | 269.70 | 452.70 | PC/GF-like Black TWD/kg | 2200
Known gas/optical subtotal | 140.00 | 390.00 | Aqua 8K Gray TWD/kg | 1090
Unquoted gas/optical rows | 3 | 3 | Aqua Clear Plus TWD/kg | 940
Known partial cost per device | 66748.69 | 67181.69
Complete device material cost | Unquoted | Unquoted
Unquoted shared equipment rows | 5 | 5
Complete reproducible system cost | Unquoted | Unquoted
Quote includes design/setup. 65,625 is not a production unit price; PCB component rows are not added again.
Known partial cost is not the full price. Missing quotes stay blank, not zero.
Consumed-material cost differs from package purchase cash cost. Shipping, tax differences and labor excluded.
Integral perforated cap is for dry testing. Accessible two-part cap option gives 9 operating prints.
Accessible cap substitutes 2 M3x12 thumbscrews and an extra cut gasket; do not add both cap options.
Liquids are separate; gas is shared. Four valve sets and extra status LEDs are not purchased.
Core/GasOptics are per-device; SharedLab is shared; Conditional depends on testing.
Price basis: saved 2026-09-25 listings and allowances, not a fresh supplier quote.

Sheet: Printed
STL printing and resin
STL | Material | Qty | cm3 | Resin g | TWD/kg | Cost TWD
01_integrated_body.stl | PC/GF-like Black | 1 | 122.84 | 182.42 | 2200.00 | 401.33 | Use specified resin; support geometry not included. Budget assumes 1.35 waste factor.
02_service_tray.stl | Aqua 8K Gray | 1 | 44.66 | 66.31 | 1090.00 | 72.28 | Use specified resin; support geometry not included. Budget assumes 1.35 waste factor.
03_hinged_lid.stl | PC/GF-like Black | 1 | 62.42 | 92.70 | 2200.00 | 203.94 | Use specified resin; support geometry not included. Budget assumes 1.35 waste factor.
04_common_gas_optical_cap.stl | PC/GF-like Black | 1 | 10.85 | 16.11 | 2200.00 | 35.44 | Use specified resin; support geometry not included. Budget assumes 1.35 waste factor.
05_well_NE_CLEAR.stl | Aqua Clear Plus (test) | 1 | 0.18 | 0.27 | 940.00 | 0.25 | Monolithic flat floor; 0.5 mm bottom, 150 uL nominal. Material and fit prototype.
05_well_NW_CLEAR.stl | Aqua Clear Plus (test) | 1 | 0.18 | 0.27 | 940.00 | 0.25 | Monolithic flat floor; 0.5 mm bottom, 150 uL nominal. Material and fit prototype.
05_well_SE_CLEAR.stl | Aqua Clear Plus (test) | 1 | 0.18 | 0.27 | 940.00 | 0.25 | Monolithic flat floor; 0.5 mm bottom, 150 uL nominal. Material and fit prototype.
05_well_SW_CLEAR.stl | Aqua Clear Plus (test) | 1 | 0.18 | 0.27 | 940.00 | 0.25 | Monolithic flat floor; 0.5 mm bottom, 150 uL nominal. Material and fit prototype.
Alternative to 04: these two replace the integral cap, excluded from eight-part total.
OPTION/04_split_lower_BLACK.stl | PC/GF-like Black | 1 | 5.90 | 8.76 | 2200.00 | 19.27
OPTION/04_split_upper_BLACK.stl | PC/GF-like Black | 1 | 4.99 | 7.40 | 2200.00 | 16.29

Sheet: Purchase
Purchased and shared items
ID | Scope | Item | Qty | Unit low | Unit high | Subtotal low | Subtotal high | Price status | Specification | Source and date
F01 | Core | fan | 1 | 161.70 | 161.70 | 161.70 | 161.70 | Budget/listing | Sunon MF40100V1-1000U-A99 candidate;32 mm hole pitch;max157 mA. Wiring/current capacity must be checked. | RS 2025400 viewed 2026-09-24 incl tax; out of stock then. https://twcn.rs-online.com/web/p/axial-fans/2025400
H01 | Core | M3×10 socket screw | 8 | 2.00 | 5.00 | 16.00 | 40.00 | Budget/listing | 4 base-to-body +4 PCB-to-posts. PCB uses .5 mm flat washer. Verify pad keep-out; no self-tapping resin. | Planning allowance, NOT supplier quote
H03 | Core | M3×10 thumb screw | 2 | 8.00 | 20.00 | 16.00 | 40.00 | Budget/listing | Common cap ears to deck; bottom against hard stops, not torque on well. | Planning allowance, NOT supplier quote
H04 | Core | M3×12 thumb screw | 1 | 8.00 | 20.00 | 8.00 | 20.00 | Budget/listing | Outer lid front; one screw, no outer gasket. | Planning allowance, NOT supplier quote
H05 | Core | M3 hex nuts | 11 | 1.00 | 3.00 | 11.00 | 33.00 | Budget/listing | 4 body +4 PCB +2 cap +1 lid. AF5.5, nominal thickness2.4 mm. | Planning allowance, NOT supplier quote
H06 | Core | M3 flat washers | 4 | 1.00 | 3.00 | 4.00 | 12.00 | Budget/listing | PCB screw heads only; nominal ID3.2 OD7 thickness.5; actual PCB keep-out must pass. | Planning allowance, NOT supplier quote
H07 | Core | M3×75 hinge bolt + nyloc nut | 1 | 20.00 | 60.00 | 20.00 | 60.00 | Budget/listing | Straight 3 mm shaft through hinge; partially threaded preferred. End nut only retains pin; do not clamp plastic barrels. | Planning allowance, NOT supplier quote
H08 | Core | M3 flat washers | 2 | 1.00 | 3.00 | 2.00 | 6.00 | Budget/listing | Hinge ends; keep axial free play, support bolt during insertion. | Planning allowance, NOT supplier quote
H09 | Core | M4×20 screw + nut + washer set | 4 | 4.00 | 10.00 | 16.00 | 40.00 | Budget/listing | Floor3 + fan10 + washer + nut; full nut engagement. Upper fixing envelope toZ20 leaves16 mm maximum component height with2 mm margin locally. Fan holes4.3 mm. | Planning allowance, NOT supplier quote
E01 | Core | Fan wiring harness / lead | 1 | 15.00 | 40.00 | 15.00 | 40.00 | Budget/listing | Compatible 5 V board/bench supply connection, reverse-polarity prevention, insulation. No extra panel switch or status LED. | Planning allowance, NOT supplier quote
S01 | GasOptics | opaque silicone sheet | 1 | 50.00 | 150.00 | 50.00 | 150.00 | Budget/listing | 0.8 mm stock, cut ONE four-aperture well gasket + ONE PD ring. Low fluorescence; gas/VOC compatibility and compression recovery require qualification. | Planning allowance, NOT supplier quote
S02 | GasOptics | opaque dry tape | 1 | 10.00 | 40.00 | 10.00 | 40.00 | Budget/listing | Filter corner retention / hose strain relief only; do not cover optical aperture or contact liquid/gas lumen. Use existing stock if suitable. | Planning allowance, NOT supplier quote
G01 | GasOptics | hydrophobic gas filter | 2 |  |  | Unquoted | Unquoted | Unquoted | Inlet and exhaust, one each; gas-rated, compatible fittings, low backpressure at intended flow. Vendor data and VOC recovery needed. Exact SKU TBD. | Planning allowance, NOT supplier quote
G02 | GasOptics | PTFE tube, 1 m cut length | 1 | 80.00 | 200.00 | 80.00 | 200.00 | Budget/listing | Nominal ID2 OD3 mm; routing outside enclosure, avoid inlet/outlet swaps. Do not assume universal filter fitting compatibility. | Planning allowance, NOT supplier quote
G03 | GasOptics | short coupling kit | 1 |  |  | Unquoted | Unquoted | Unquoted | 2 ×30 mm silicone ID3 OD5 sleeves on integrated OD3.4/4.0 tails to PTFE OD3. Filter-end adapters and mechanical retention selected with filter SKU; VOC adsorption test required. | Planning allowance, NOT supplier quote
O01 | GasOptics | custom emission filter | 1 |  |  | Unquoted | Unquoted | Unquoted | MAX5.2×4.2×1.0 mm; no off-the-shelf match verified. Specify spectral OD over full LED band & incidence cone, fluorescence transmission and angle shift. MC proxy T470=1e-5,T520=.9 is NOT a purchase spec guarantee. | Planning allowance, NOT supplier quote
G04 | Conditional | shared condensate trap | 1 |  |  | Unquoted | Unquoted | Unquoted | Add only if elevated exhaust routing + operating conditions still permit filter wetting. No wet/blocked exhaust operation. Unpriced; qualification decides necessity. | Planning allowance, NOT supplier quote
E02 | SharedLab | power source | 1 |  |  | Unquoted | Unquoted | Unquoted | Use existing PCB-compatible source only after vendor confirms input and current. No new panel power jack presumed; not included twice in PCB cost. | Planning allowance, NOT supplier quote
L01 | SharedLab | gas bench | 1 |  |  | Unquoted | Unquoted | Unquoted | External flow/pressure control + independent pressure limit, measured filter pressure curve. Shared lab apparatus not free in reproduction cost. | Planning allowance, NOT supplier quote
L02 | SharedLab | workshop equipment | 1 |  |  | Unquoted | Unquoted | Unquoted | Printer, wash/cure equipment, resin-approved cleaning materials, PPE, hex key, tweezers, caliper, feeler gauge; use existing qualified equipment. | Planning allowance, NOT supplier quote
L03 | SharedLab | validation facilities | 1 |  |  | Unquoted | Unquoted | Unquoted | Spectral transmission/background measurement, calibrated optical power/current, temperature/CO2/humidity context, approved HEK293T laboratory procedures. | Planning allowance, NOT supplier quote
P01 | SharedLab | USB-UART 3.3 V logic adapter | 1 |  |  | Unquoted | Unquoted | Unquoted | For J3 flashing; verify pin order and RX routing with vendor. Do not apply 5 V to ESP32 UART or power from UART VCC when main supply is connected. | Required programming tool if not already available; quotation pending.

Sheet: PCB
PCB vendor BOM: all 61 rows
Row | Reference | Qty | Vendor value/MPN | Completeness | Spare unit TWD | Spare subtotal
1 | C1 | 1 |  | Missing value/MPN |  | Unquoted | NTHU_TEST_BOARD_BOM.docx vendor table row 1
2 | C2 | 1 |  | Missing value/MPN |  | Unquoted | NTHU_TEST_BOARD_BOM.docx vendor table row 2
3 | C3 | 1 |  | Missing value/MPN |  | Unquoted | NTHU_TEST_BOARD_BOM.docx vendor table row 3
4 | C4 | 1 |  | Missing value/MPN |  | Unquoted | NTHU_TEST_BOARD_BOM.docx vendor table row 4
5 | C5 | 1 |  | Missing value/MPN |  | Unquoted | NTHU_TEST_BOARD_BOM.docx vendor table row 5
6 | C6 | 1 |  | Missing value/MPN |  | Unquoted | NTHU_TEST_BOARD_BOM.docx vendor table row 6
7 | C7 | 1 |  | Missing value/MPN |  | Unquoted | NTHU_TEST_BOARD_BOM.docx vendor table row 7
8 | C8 | 1 |  | Missing value/MPN |  | Unquoted | NTHU_TEST_BOARD_BOM.docx vendor table row 8
9 | C9 | 1 |  | Missing value/MPN |  | Unquoted | NTHU_TEST_BOARD_BOM.docx vendor table row 9
10 | C10 | 1 |  | Missing value/MPN |  | Unquoted | NTHU_TEST_BOARD_BOM.docx vendor table row 10
11 | C11 | 1 |  | Missing value/MPN |  | Unquoted | NTHU_TEST_BOARD_BOM.docx vendor table row 11
12 | C12 | 1 | 47uF | As listed; package/height to verify |  | Unquoted | NTHU_TEST_BOARD_BOM.docx vendor table row 12
13 | C13,C18 | 2 | 22uF | As listed; package/height to verify |  | Unquoted | NTHU_TEST_BOARD_BOM.docx vendor table row 13
14 | C14,C15,C22,C25 | 4 | 0.1uF | As listed; package/height to verify |  | Unquoted | NTHU_TEST_BOARD_BOM.docx vendor table row 14
15 | C16,C17,C23,C28 | 4 | 10uF | As listed; package/height to verify |  | Unquoted | NTHU_TEST_BOARD_BOM.docx vendor table row 15
16 | C19,C20,C27,C29 | 4 | 1uF | As listed; package/height to verify |  | Unquoted | NTHU_TEST_BOARD_BOM.docx vendor table row 16
17 | C21 | 1 | 2.2pF | As listed; package/height to verify |  | Unquoted | NTHU_TEST_BOARD_BOM.docx vendor table row 17
18 | C24 | 1 | 1000pF | As listed; package/height to verify |  | Unquoted | NTHU_TEST_BOARD_BOM.docx vendor table row 18
19 | C26 | 1 | 100uF | As listed; package/height to verify |  | Unquoted | NTHU_TEST_BOARD_BOM.docx vendor table row 19
20 | DPS1,DPS2 | 2 | LED | As listed; package/height to verify |  | Unquoted | NTHU_TEST_BOARD_BOM.docx vendor table row 20
21 | D1,D2,D3,D4 | 4 | 155124BS73200 | As listed; package/height to verify |  | Unquoted | NTHU_TEST_BOARD_BOM.docx vendor table row 21
22 | D5 | 1 | VEMD5060X01 | As listed; package/height to verify |  | Unquoted | NTHU_TEST_BOARD_BOM.docx vendor table row 22
23 | FD1,FD2,FD3,FD4,FD5,FD6,FD7,FD8 | 8 | FD_040(SMT用光學點) | As listed; package/height to verify |  | Unquoted | NTHU_TEST_BOARD_BOM.docx vendor table row 23
24 | H1,H2,H3,H4 | 4 | CON(銅柱孔) | As listed; package/height to verify |  | Unquoted | NTHU_TEST_BOARD_BOM.docx vendor table row 24
25 | J1 | 1 | Battery_Case | As listed; package/height to verify |  | Unquoted | NTHU_TEST_BOARD_BOM.docx vendor table row 25
26 | J2 | 1 | USB TYPE C FEMALE | As listed; package/height to verify |  | Unquoted | NTHU_TEST_BOARD_BOM.docx vendor table row 26
27 | J3 | 1 | CON4(4pin排針) | As listed; package/height to verify |  | Unquoted | NTHU_TEST_BOARD_BOM.docx vendor table row 27
28 | L1 | 1 |  | Missing value/MPN |  | Unquoted | NTHU_TEST_BOARD_BOM.docx vendor table row 28
29 | Q1,Q2,Q3,Q4 | 4 | AO3400A | As listed; package/height to verify |  | Unquoted | NTHU_TEST_BOARD_BOM.docx vendor table row 29
30 | R1 | 1 |  | Missing value/MPN |  | Unquoted | NTHU_TEST_BOARD_BOM.docx vendor table row 30
31 | R2 | 1 |  | Missing value/MPN |  | Unquoted | NTHU_TEST_BOARD_BOM.docx vendor table row 31
32 | R3 | 1 |  | Missing value/MPN |  | Unquoted | NTHU_TEST_BOARD_BOM.docx vendor table row 32
33 | R4 | 1 |  | Missing value/MPN |  | Unquoted | NTHU_TEST_BOARD_BOM.docx vendor table row 33
34 | R5 | 1 |  | Missing value/MPN |  | Unquoted | NTHU_TEST_BOARD_BOM.docx vendor table row 34
35 | R6 | 1 |  | Missing value/MPN |  | Unquoted | NTHU_TEST_BOARD_BOM.docx vendor table row 35
36 | R7 | 1 |  | Missing value/MPN |  | Unquoted | NTHU_TEST_BOARD_BOM.docx vendor table row 36
37 | R8 | 1 |  | Missing value/MPN |  | Unquoted | NTHU_TEST_BOARD_BOM.docx vendor table row 37
38 | R9 | 1 |  | Missing value/MPN |  | Unquoted | NTHU_TEST_BOARD_BOM.docx vendor table row 38
39 | R10 | 1 |  | Missing value/MPN |  | Unquoted | NTHU_TEST_BOARD_BOM.docx vendor table row 39
40 | R11 | 1 |  | Missing value/MPN |  | Unquoted | NTHU_TEST_BOARD_BOM.docx vendor table row 40
41 | R12 | 1 |  | Missing value/MPN |  | Unquoted | NTHU_TEST_BOARD_BOM.docx vendor table row 41
42 | R13 | 1 |  | Missing value/MPN |  | Unquoted | NTHU_TEST_BOARD_BOM.docx vendor table row 42
43 | R14 | 1 |  | Missing value/MPN |  | Unquoted | NTHU_TEST_BOARD_BOM.docx vendor table row 43
44 | R15,R28,R35 | 3 | 10k | As listed; package/height to verify |  | Unquoted | NTHU_TEST_BOARD_BOM.docx vendor table row 44
45 | R16,R21,R24,R29,R30,R31,R36 | 7 | 100R | As listed; package/height to verify |  | Unquoted | NTHU_TEST_BOARD_BOM.docx vendor table row 45
46 | R17,R22,R25,R32 | 4 | 220R | As listed; package/height to verify |  | Unquoted | NTHU_TEST_BOARD_BOM.docx vendor table row 46
47 | R20,R23,R26,R33 | 4 | 100k | As listed; package/height to verify |  | Unquoted | NTHU_TEST_BOARD_BOM.docx vendor table row 47
48 | R27 | 1 | 100M | As listed; package/height to verify |  | Unquoted | NTHU_TEST_BOARD_BOM.docx vendor table row 48
49 | R34 | 1 | 0.1R | As listed; package/height to verify |  | Unquoted | NTHU_TEST_BOARD_BOM.docx vendor table row 49
50 | R37,R38 | 2 | 47R | As listed; package/height to verify |  | Unquoted | NTHU_TEST_BOARD_BOM.docx vendor table row 50
51 | SW1 | 1 | SW1 | As listed; package/height to verify |  | Unquoted | NTHU_TEST_BOARD_BOM.docx vendor table row 51
52 | SW2,SW3 | 2 | Tactile_Switch | As listed; package/height to verify |  | Unquoted | NTHU_TEST_BOARD_BOM.docx vendor table row 52
53 | U1 | 1 | TPS61023 | As listed; package/height to verify |  | Unquoted | NTHU_TEST_BOARD_BOM.docx vendor table row 53
54 | U2 | 1 | BQ24074 | As listed; package/height to verify |  | Unquoted | NTHU_TEST_BOARD_BOM.docx vendor table row 54
55 | U3 | 1 |  | Missing value/MPN |  | Unquoted | NTHU_TEST_BOARD_BOM.docx vendor table row 55
56 | U4 | 1 | ESP32-WROOM-32E | As listed; package/height to verify |  | Unquoted | NTHU_TEST_BOARD_BOM.docx vendor table row 56
57 | U5 | 1 | EC50117KBG | As listed; package/height to verify |  | Unquoted | NTHU_TEST_BOARD_BOM.docx vendor table row 57
58 | U6 | 1 | LP5907MFX-3.3/NOPB | As listed; package/height to verify |  | Unquoted | NTHU_TEST_BOARD_BOM.docx vendor table row 58
59 | U7 | 1 | LTC6655BHMS8-2.5#PBF | As listed; package/height to verify |  | Unquoted | NTHU_TEST_BOARD_BOM.docx vendor table row 59
60 | U8 | 1 | LMP7721 | As listed; package/height to verify |  | Unquoted | NTHU_TEST_BOARD_BOM.docx vendor table row 60
61 | U9 | 1 | ADS8866IDGS | As listed; package/height to verify |  | Unquoted | NTHU_TEST_BOARD_BOM.docx vendor table row 61

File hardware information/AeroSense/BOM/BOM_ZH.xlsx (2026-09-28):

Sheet: Summary
AeroSense 完整材料成本
項目 | 低估算 TWD | 高估算 TWD | 可修改假設 | Value
PCB兩片報價（含設計／開機） | 131250.00 | 131250.00 | PCB報價片數 | 2
本次報價平均每片 | 65625.00 | 65625.00 | 樹脂密度 g/cm3 | 1.1
八件列印耗材分攤 | 713.99 | 713.99 | 支撐與損耗倍率 | 1.35
核心五金與風扇 | 269.70 | 452.70 | PC/GF-like Black TWD/kg | 2200
光學／氣路已估价小計 | 140.00 | 390.00 | Aqua 8K Gray TWD/kg | 1090
光學／氣路缺報價列數 | 3 | 3 | Aqua Clear Plus TWD/kg | 940
已知單機部分成本 | 66748.69 | 67181.69
完整單機材料成本 | 待報價 | 待報價
共用設備缺報價列數 | 5 | 5
完整重現系統成本 | 待報價 | 待報價
報價包含設計及開機。65,625不是量產單價；PCB子料不重複加總。
已知部分成本不是完整總價。未知價格留白，不用0替代。
耗材分攤不等於整瓶或整包購買的现金支出，未含運費、稅差及工時。
孔板一體內蓋供乾式測試。可清潔二件內蓋替代時總列印件數9。
二件內蓋改用2顆M3×12手轉螺絲、另裁1片密封圈；不得與原內蓋同時加算。
各井液體分開、氣相共用。沒有加購四組氣閥或額外狀態燈。
Core／GasOptics是每台材料；SharedLab可共用；Conditional需試驗判斷。
價格基準：2026-09-25既有標價與預算，非本次供應商報價。

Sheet: Printed
STL 列印清單與耗材
STL | 材料 | 數量 | cm3 | 估計耗材 g | 單價 TWD/kg | 分攤 TWD
01_integrated_body.stl | PC/GF-like Black | 1 | 122.84 | 182.42 | 2200.00 | 401.33 | 按組裝手冊用指定樹脂；未列支撐模型，成本已含1.35損耗假設。
02_service_tray.stl | Aqua 8K Gray | 1 | 44.66 | 66.31 | 1090.00 | 72.28 | 按組裝手冊用指定樹脂；未列支撐模型，成本已含1.35損耗假設。
03_hinged_lid.stl | PC/GF-like Black | 1 | 62.42 | 92.70 | 2200.00 | 203.94 | 按組裝手冊用指定樹脂；未列支撐模型，成本已含1.35損耗假設。
04_common_gas_optical_cap.stl | PC/GF-like Black | 1 | 10.85 | 16.11 | 2200.00 | 35.44 | 按組裝手冊用指定樹脂；未列支撐模型，成本已含1.35損耗假設。
05_well_NE_CLEAR.stl | Aqua Clear Plus (test) | 1 | 0.18 | 0.27 | 940.00 | 0.25 | 一體平底井；0.5 mm底厚、150 µL名目液量；只供材料與試裝驗證。
05_well_NW_CLEAR.stl | Aqua Clear Plus (test) | 1 | 0.18 | 0.27 | 940.00 | 0.25 | 一體平底井；0.5 mm底厚、150 µL名目液量；只供材料與試裝驗證。
05_well_SE_CLEAR.stl | Aqua Clear Plus (test) | 1 | 0.18 | 0.27 | 940.00 | 0.25 | 一體平底井；0.5 mm底厚、150 µL名目液量；只供材料與試裝驗證。
05_well_SW_CLEAR.stl | Aqua Clear Plus (test) | 1 | 0.18 | 0.27 | 940.00 | 0.25 | 一體平底井；0.5 mm底厚、150 µL名目液量；只供材料與試裝驗證。
替代04：下列兩件取代原一件，不加進八件總和。
OPTION/04_split_lower_BLACK.stl | PC/GF-like Black | 1 | 5.90 | 8.76 | 2200.00 | 19.27
OPTION/04_split_upper_BLACK.stl | PC/GF-like Black | 1 | 4.99 | 7.40 | 2200.00 | 16.29

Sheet: Purchase
其他採購與共用設備
ID | 範圍 | 品名 | 數量 | 單價低 | 單價高 | 小計低 | 小計高 | 價格狀態 | 規格與條件 | 價格來源與日期
F01 | Core | 5 V 40×40×10 mm 風扇 | 1 | 161.70 | 161.70 | 161.70 | 161.70 | 預算／標價 | 5V、40×40×10 mm，孔距32 mm。候選最大157 mA；需廠商確認供電及接法。 | RS 2025400 viewed 2026-09-24 incl tax; out of stock then. https://twcn.rs-online.com/web/p/axial-fans/2025400
H01 | Core | M3×10 內六角螺絲 | 8 | 2.00 | 5.00 | 16.00 | 40.00 | 預算／標價 | 8顆：4顆固定底座、4顆固定PCB；PCB配0.5 mm墊片。 | Planning allowance, NOT supplier quote / 預算假設，非報價
H03 | Core | M3×10 手轉螺絲 | 2 | 8.00 | 20.00 | 16.00 | 40.00 | 預算／標價 | 2顆固定一體內蓋，壓到硬止擋即可。 | Planning allowance, NOT supplier quote / 預算假設，非報價
H04 | Core | M3×12 手轉螺絲 | 1 | 8.00 | 20.00 | 8.00 | 20.00 | 預算／標價 | 1顆固定外蓋前端，不加外蓋氣密條。 | Planning allowance, NOT supplier quote / 預算假設，非報價
H05 | Core | M3 六角螺帽 | 11 | 1.00 | 3.00 | 11.00 | 33.00 | 預算／標價 | 11顆：殼4、PCB4、內蓋2、外蓋1；對邊5.5 mm。 | Planning allowance, NOT supplier quote / 預算假設，非報價
H06 | Core | M3 平墊片 | 4 | 1.00 | 3.00 | 4.00 | 12.00 | 預算／標價 | 4片僅用於PCB螺絲頭，內徑3.2、外徑7、厚0.5 mm；確認板上避空。 | Planning allowance, NOT supplier quote / 預算假設，非報價
H07 | Core | M3×75 鉸鏈螺栓＋防鬆螺帽 | 1 | 20.00 | 60.00 | 20.00 | 60.00 | 預算／標價 | 3 mm直桿穿過鉸鏈；螺帽只防滑出，勿夾緊樹脂。 | Planning allowance, NOT supplier quote / 預算假設，非報價
H08 | Core | M3 鉸鏈墊片 | 2 | 1.00 | 3.00 | 2.00 | 6.00 | 預算／標價 | 鉸鏈兩端各1片，保留軸向自由間隙。 | Planning allowance, NOT supplier quote / 預算假設，非報價
H09 | Core | M4×20 風扇固定組 | 4 | 4.00 | 10.00 | 16.00 | 40.00 | 預算／標價 | 4組固定風扇；螺絲與螺帽最高Z20，局部PCB底面元件容許高度16 mm。 | Planning allowance, NOT supplier quote / 預算假設，非報價
E01 | Core | 5 V 接線與絕緣 | 1 | 15.00 | 40.00 | 15.00 | 40.00 | 預算／標價 | 相容5V接線、絕緣及防拉扯；需確認焊點，沒有假設現成風扇插座。 | Planning allowance, NOT supplier quote / 預算假設，非報價
S01 | GasOptics | 0.8 mm 不透光矽膠片 | 1 | 50.00 | 150.00 | 50.00 | 150.00 | 預算／標價 | 0.8 mm不透光矽膠片，裁四孔井密封片與PD圈，壓縮至0.6 mm。需驗證螢光、氣味吸附與回彈。 | Planning allowance, NOT supplier quote / 預算假設，非報價
S02 | GasOptics | 乾區濾片固定材料 | 1 | 10.00 | 40.00 | 10.00 | 40.00 | 預算／標價 | 只在乾區固定濾片角落與線材；不能覆蓋光孔或接觸液體／氣流。 | Planning allowance, NOT supplier quote / 預算假設，非報價
G01 | GasOptics | 疏水 0.2 µm 氣體濾器 | 2 |  |  | 待報價 | 待報價 | 待報價 | 進、排氣各1個疏水0.2 µm氣體濾器；型號待選，需確認壓降、接頭及氣味回收率。 | Planning allowance, NOT supplier quote / 預算假設，非報價
G02 | GasOptics | PTFE 氣管 | 1 | 80.00 | 200.00 | 80.00 | 200.00 | 預算／標價 | PTFE管1 m裁切，內徑2外徑3 mm；濾器接頭不保證通用。 | Planning allowance, NOT supplier quote / 預算假設，非報價
G03 | GasOptics | 軟管與接頭轉接組 | 1 |  |  | 待報價 | 待報價 | 待報價 | 兩段約30 mm矽膠軟管，內徑3外徑5，銜接外徑3.4/4接尾及PTFE。濾器轉接頭隨型號選。 | Planning allowance, NOT supplier quote / 預算假設，非報價
O01 | GasOptics | 螢光偵測濾光片 | 1 |  |  | 待報價 | 待報價 | 待報價 | 濾片最大5.2×4.2×1.0 mm。須以LED完整波段與入射角範圍規範阻擋及透過率；尚無已確認現貨型號。 | Planning allowance, NOT supplier quote / 預算假設，非報價
G04 | Conditional | 冷凝捕集器（視測試結果） | 1 |  |  | 待報價 | 待報價 | 待報價 | 只有排气冷凝確實造成濾器濕潤時才增加；仍不得在排氣阻塞下運作。 | Planning allowance, NOT supplier quote / 預算假設，非報價
E02 | SharedLab | PCB 電源／電池／線材 | 1 |  |  | 待報價 | 待報價 | 待報價 | 相容PCB電源／電池／線材，由廠商確認輸入及電流，使用現有設備可不重複購買。 | Planning allowance, NOT supplier quote / 預算假設，非報價
L01 | SharedLab | 氣流來源與量測限壓設備 | 1 |  |  | 待報價 | 待報價 | 待報價 | 外接流量來源、流量計、壓力計與獨立限壓；屬可共用設備，並非免費。 | Planning allowance, NOT supplier quote / 預算假設，非報價
L02 | SharedLab | 列印後處理及組裝工具 | 1 |  |  | 待報價 | 待報價 | 待報價 | 列印、清洗、固化、量具、六角匙、鑷子及樹脂防護用品；使用現有合格設備。 | Planning allowance, NOT supplier quote / 預算假設，非報價
L03 | SharedLab | 光學校正及細胞實驗設備 | 1 |  |  | 待報價 | 待報價 | 待報價 | 光譜穿透／背景量測、功率／電流校正及溫濕度／CO2控制、HEK293T實驗設備。 | Planning allowance, NOT supplier quote / 預算假設，非報價
P01 | SharedLab | 3.3 V 邏輯 USB-UART 燒錄器 | 1 |  |  | 待報價 | 待報價 | 待報價 | 燒錄J3用3.3V邏輯USB-UART，接腳及RX線路須廠商確認。不可對UART送入5V。 | Required programming tool if not already available; quotation pending.

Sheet: PCB
PCB 廠商完整61列
原列 | Reference | 數量 | 原值／料號 | 完整性 | 備料單價 | 備料小計
1 | C1 | 1 |  | 廠商未提供完整值／MPN |  | 待報價 | NTHU_TEST_BOARD_BOM.docx vendor table row 1
2 | C2 | 1 |  | 廠商未提供完整值／MPN |  | 待報價 | NTHU_TEST_BOARD_BOM.docx vendor table row 2
3 | C3 | 1 |  | 廠商未提供完整值／MPN |  | 待報價 | NTHU_TEST_BOARD_BOM.docx vendor table row 3
4 | C4 | 1 |  | 廠商未提供完整值／MPN |  | 待報價 | NTHU_TEST_BOARD_BOM.docx vendor table row 4
5 | C5 | 1 |  | 廠商未提供完整值／MPN |  | 待報價 | NTHU_TEST_BOARD_BOM.docx vendor table row 5
6 | C6 | 1 |  | 廠商未提供完整值／MPN |  | 待報價 | NTHU_TEST_BOARD_BOM.docx vendor table row 6
7 | C7 | 1 |  | 廠商未提供完整值／MPN |  | 待報價 | NTHU_TEST_BOARD_BOM.docx vendor table row 7
8 | C8 | 1 |  | 廠商未提供完整值／MPN |  | 待報價 | NTHU_TEST_BOARD_BOM.docx vendor table row 8
9 | C9 | 1 |  | 廠商未提供完整值／MPN |  | 待報價 | NTHU_TEST_BOARD_BOM.docx vendor table row 9
10 | C10 | 1 |  | 廠商未提供完整值／MPN |  | 待報價 | NTHU_TEST_BOARD_BOM.docx vendor table row 10
11 | C11 | 1 |  | 廠商未提供完整值／MPN |  | 待報價 | NTHU_TEST_BOARD_BOM.docx vendor table row 11
12 | C12 | 1 | 47uF | 依廠商列示；封裝／高度仍需確認 |  | 待報價 | NTHU_TEST_BOARD_BOM.docx vendor table row 12
13 | C13,C18 | 2 | 22uF | 依廠商列示；封裝／高度仍需確認 |  | 待報價 | NTHU_TEST_BOARD_BOM.docx vendor table row 13
14 | C14,C15,C22,C25 | 4 | 0.1uF | 依廠商列示；封裝／高度仍需確認 |  | 待報價 | NTHU_TEST_BOARD_BOM.docx vendor table row 14
15 | C16,C17,C23,C28 | 4 | 10uF | 依廠商列示；封裝／高度仍需確認 |  | 待報價 | NTHU_TEST_BOARD_BOM.docx vendor table row 15
16 | C19,C20,C27,C29 | 4 | 1uF | 依廠商列示；封裝／高度仍需確認 |  | 待報價 | NTHU_TEST_BOARD_BOM.docx vendor table row 16
17 | C21 | 1 | 2.2pF | 依廠商列示；封裝／高度仍需確認 |  | 待報價 | NTHU_TEST_BOARD_BOM.docx vendor table row 17
18 | C24 | 1 | 1000pF | 依廠商列示；封裝／高度仍需確認 |  | 待報價 | NTHU_TEST_BOARD_BOM.docx vendor table row 18
19 | C26 | 1 | 100uF | 依廠商列示；封裝／高度仍需確認 |  | 待報價 | NTHU_TEST_BOARD_BOM.docx vendor table row 19
20 | DPS1,DPS2 | 2 | LED | 依廠商列示；封裝／高度仍需確認 |  | 待報價 | NTHU_TEST_BOARD_BOM.docx vendor table row 20
21 | D1,D2,D3,D4 | 4 | 155124BS73200 | 依廠商列示；封裝／高度仍需確認 |  | 待報價 | NTHU_TEST_BOARD_BOM.docx vendor table row 21
22 | D5 | 1 | VEMD5060X01 | 依廠商列示；封裝／高度仍需確認 |  | 待報價 | NTHU_TEST_BOARD_BOM.docx vendor table row 22
23 | FD1,FD2,FD3,FD4,FD5,FD6,FD7,FD8 | 8 | FD_040(SMT用光學點) | 依廠商列示；封裝／高度仍需確認 |  | 待報價 | NTHU_TEST_BOARD_BOM.docx vendor table row 23
24 | H1,H2,H3,H4 | 4 | CON(銅柱孔) | 依廠商列示；封裝／高度仍需確認 |  | 待報價 | NTHU_TEST_BOARD_BOM.docx vendor table row 24
25 | J1 | 1 | Battery_Case | 依廠商列示；封裝／高度仍需確認 |  | 待報價 | NTHU_TEST_BOARD_BOM.docx vendor table row 25
26 | J2 | 1 | USB TYPE C FEMALE | 依廠商列示；封裝／高度仍需確認 |  | 待報價 | NTHU_TEST_BOARD_BOM.docx vendor table row 26
27 | J3 | 1 | CON4(4pin排針) | 依廠商列示；封裝／高度仍需確認 |  | 待報價 | NTHU_TEST_BOARD_BOM.docx vendor table row 27
28 | L1 | 1 |  | 廠商未提供完整值／MPN |  | 待報價 | NTHU_TEST_BOARD_BOM.docx vendor table row 28
29 | Q1,Q2,Q3,Q4 | 4 | AO3400A | 依廠商列示；封裝／高度仍需確認 |  | 待報價 | NTHU_TEST_BOARD_BOM.docx vendor table row 29
30 | R1 | 1 |  | 廠商未提供完整值／MPN |  | 待報價 | NTHU_TEST_BOARD_BOM.docx vendor table row 30
31 | R2 | 1 |  | 廠商未提供完整值／MPN |  | 待報價 | NTHU_TEST_BOARD_BOM.docx vendor table row 31
32 | R3 | 1 |  | 廠商未提供完整值／MPN |  | 待報價 | NTHU_TEST_BOARD_BOM.docx vendor table row 32
33 | R4 | 1 |  | 廠商未提供完整值／MPN |  | 待報價 | NTHU_TEST_BOARD_BOM.docx vendor table row 33
34 | R5 | 1 |  | 廠商未提供完整值／MPN |  | 待報價 | NTHU_TEST_BOARD_BOM.docx vendor table row 34
35 | R6 | 1 |  | 廠商未提供完整值／MPN |  | 待報價 | NTHU_TEST_BOARD_BOM.docx vendor table row 35
36 | R7 | 1 |  | 廠商未提供完整值／MPN |  | 待報價 | NTHU_TEST_BOARD_BOM.docx vendor table row 36
37 | R8 | 1 |  | 廠商未提供完整值／MPN |  | 待報價 | NTHU_TEST_BOARD_BOM.docx vendor table row 37
38 | R9 | 1 |  | 廠商未提供完整值／MPN |  | 待報價 | NTHU_TEST_BOARD_BOM.docx vendor table row 38
39 | R10 | 1 |  | 廠商未提供完整值／MPN |  | 待報價 | NTHU_TEST_BOARD_BOM.docx vendor table row 39
40 | R11 | 1 |  | 廠商未提供完整值／MPN |  | 待報價 | NTHU_TEST_BOARD_BOM.docx vendor table row 40
41 | R12 | 1 |  | 廠商未提供完整值／MPN |  | 待報價 | NTHU_TEST_BOARD_BOM.docx vendor table row 41
42 | R13 | 1 |  | 廠商未提供完整值／MPN |  | 待報價 | NTHU_TEST_BOARD_BOM.docx vendor table row 42
43 | R14 | 1 |  | 廠商未提供完整值／MPN |  | 待報價 | NTHU_TEST_BOARD_BOM.docx vendor table row 43
44 | R15,R28,R35 | 3 | 10k | 依廠商列示；封裝／高度仍需確認 |  | 待報價 | NTHU_TEST_BOARD_BOM.docx vendor table row 44
45 | R16,R21,R24,R29,R30,R31,R36 | 7 | 100R | 依廠商列示；封裝／高度仍需確認 |  | 待報價 | NTHU_TEST_BOARD_BOM.docx vendor table row 45
46 | R17,R22,R25,R32 | 4 | 220R | 依廠商列示；封裝／高度仍需確認 |  | 待報價 | NTHU_TEST_BOARD_BOM.docx vendor table row 46
47 | R20,R23,R26,R33 | 4 | 100k | 依廠商列示；封裝／高度仍需確認 |  | 待報價 | NTHU_TEST_BOARD_BOM.docx vendor table row 47
48 | R27 | 1 | 100M | 依廠商列示；封裝／高度仍需確認 |  | 待報價 | NTHU_TEST_BOARD_BOM.docx vendor table row 48
49 | R34 | 1 | 0.1R | 依廠商列示；封裝／高度仍需確認 |  | 待報價 | NTHU_TEST_BOARD_BOM.docx vendor table row 49
50 | R37,R38 | 2 | 47R | 依廠商列示；封裝／高度仍需確認 |  | 待報價 | NTHU_TEST_BOARD_BOM.docx vendor table row 50
51 | SW1 | 1 | SW1 | 依廠商列示；封裝／高度仍需確認 |  | 待報價 | NTHU_TEST_BOARD_BOM.docx vendor table row 51
52 | SW2,SW3 | 2 | Tactile_Switch | 依廠商列示；封裝／高度仍需確認 |  | 待報價 | NTHU_TEST_BOARD_BOM.docx vendor table row 52
53 | U1 | 1 | TPS61023 | 依廠商列示；封裝／高度仍需確認 |  | 待報價 | NTHU_TEST_BOARD_BOM.docx vendor table row 53
54 | U2 | 1 | BQ24074 | 依廠商列示；封裝／高度仍需確認 |  | 待報價 | NTHU_TEST_BOARD_BOM.docx vendor table row 54
55 | U3 | 1 |  | 廠商未提供完整值／MPN |  | 待報價 | NTHU_TEST_BOARD_BOM.docx vendor table row 55
56 | U4 | 1 | ESP32-WROOM-32E | 依廠商列示；封裝／高度仍需確認 |  | 待報價 | NTHU_TEST_BOARD_BOM.docx vendor table row 56
57 | U5 | 1 | EC50117KBG | 依廠商列示；封裝／高度仍需確認 |  | 待報價 | NTHU_TEST_BOARD_BOM.docx vendor table row 57
58 | U6 | 1 | LP5907MFX-3.3/NOPB | 依廠商列示；封裝／高度仍需確認 |  | 待報價 | NTHU_TEST_BOARD_BOM.docx vendor table row 58
59 | U7 | 1 | LTC6655BHMS8-2.5#PBF | 依廠商列示；封裝／高度仍需確認 |  | 待報價 | NTHU_TEST_BOARD_BOM.docx vendor table row 59
60 | U8 | 1 | LMP7721 | 依廠商列示；封裝／高度仍需確認 |  | 待報價 | NTHU_TEST_BOARD_BOM.docx vendor table row 60
61 | U9 | 1 | ADS8866IDGS | 依廠商列示；封裝／高度仍需確認 |  | 待報價 | NTHU_TEST_BOARD_BOM.docx vendor table row 61

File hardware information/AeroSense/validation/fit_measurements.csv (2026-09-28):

feature 項目 | nominal/limit 名目或限制 | required evidence 證據 | measured 實測 | uncertainty 不確定度 | pass/fail 判定 | reviewer 審核
PCB width/length/thickness 板尺寸 | 100 / 90 / 1.6 mm | vendor mechanical drawing
Mount-hole centers 固定孔 | (+/-45,+/-40) mm; assumed | vendor STEP/drill file
PD center offset 感光偏移 | nominal (0,-0.4) mm, sign unconfirmed | vendor package rotation and bottom-view mirror
LED emission centers 發光點 | (+/-3.3,+/-5.7); optical face Z40.2 | vendor package drawing and placement
PD package top 封裝頂 | Z40.5 mm | populated STEP
C21/R27 optical-side heights | 1.2 mm envelope assumption | exact MPN/STEP
U8 optical-side height | 1.75 mm envelope assumption | exact MPN/STEP
Battery holder plus battery 電池座含電池 | unknown; 23 mm available over fan body, 16 mm over fasteners | populated STEP and battery specification
J2 and SW1 cutout 插座開關 | check against enclosure actual mesh | connector insertion and finger-access envelope
Fan airflow and supply | 40x40x10; 5 V supply capacity unverified | vendor electrical confirmation
Filter thickness 濾片 | max 5.2x4.2x1.0 mm | supplier dimensional/spectral certificate
Printed well actual dimensions | floor0.5; wall0.55; lateral fit clearance0.15 mm/side | printed coupon and dimensional inspection
Gasket seal contact | 0.8 mm stock to 0.6 mm compressed | pressure/contact-film leak test

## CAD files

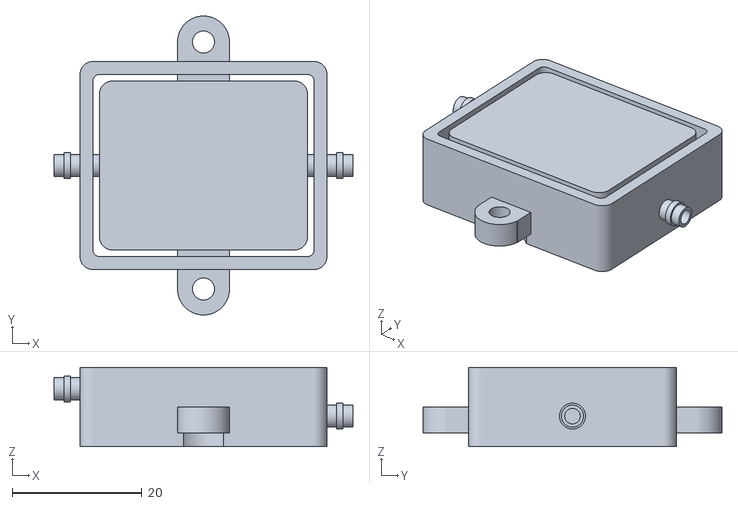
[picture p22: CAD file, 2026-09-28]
hardware information/AeroSense/CAD/assembly_coordinates/04_common_gas_optical_cap.stl
46.0 x 46.0 x 12.2

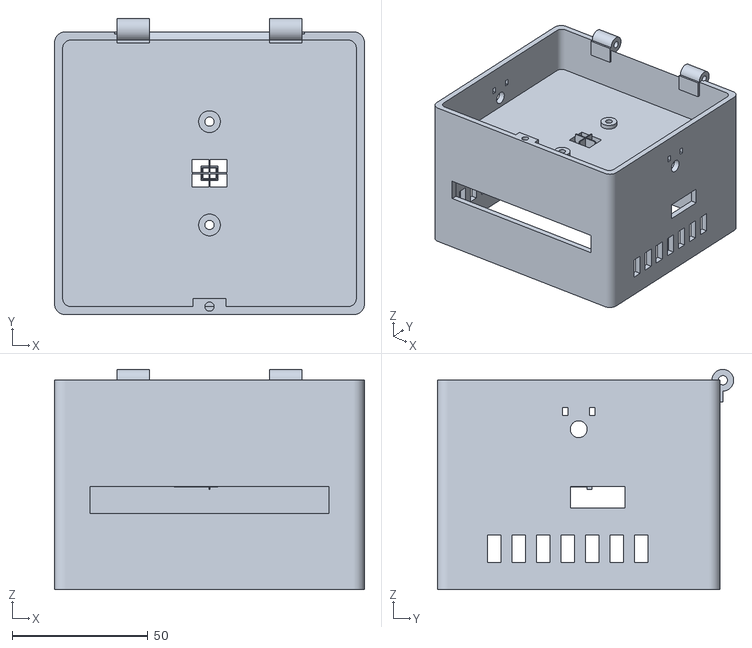
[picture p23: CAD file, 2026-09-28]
hardware information/AeroSense/CAD/inputs/body_input.stl
114.0 x 109.0 x 81.0

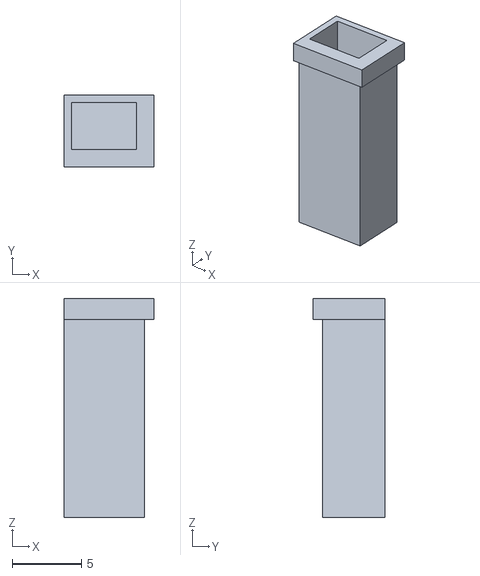
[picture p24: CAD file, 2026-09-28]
hardware information/AeroSense/STL/05_well_SE_CLEAR.stl
6.50 x 5.20 x 15.8

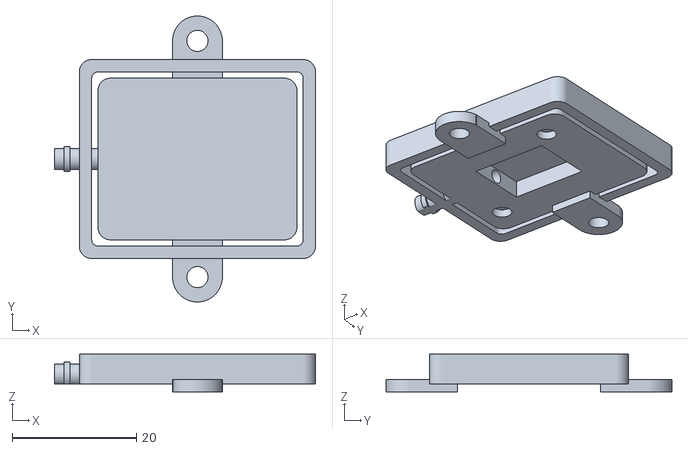
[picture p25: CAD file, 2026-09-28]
hardware information/AeroSense/STL/OPTION_accessible_cap/04_split_upper_BLACK.stl
42.0 x 46.0 x 6.10

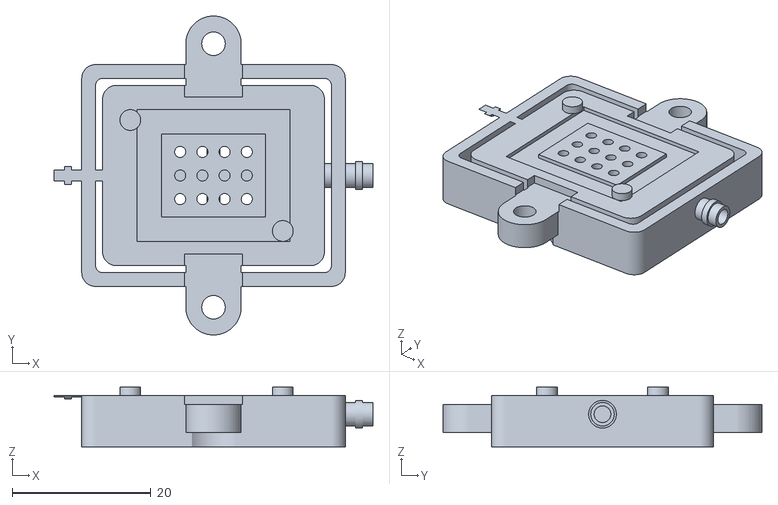
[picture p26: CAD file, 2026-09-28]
hardware information/AeroSense/STL/OPTION_accessible_cap/04_split_lower_BLACK.stl
46.0 x 46.0 x 8.60

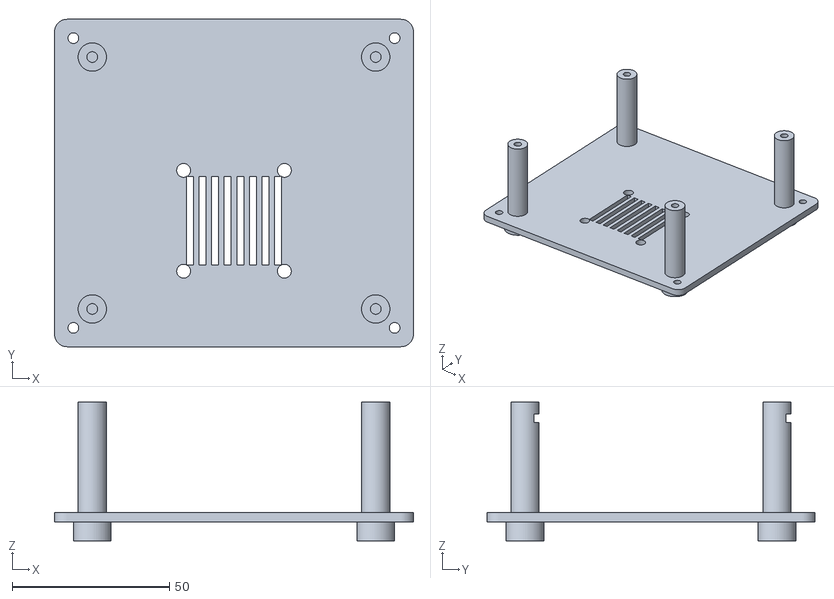
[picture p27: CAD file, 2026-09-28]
hardware information/AeroSense/CAD/assembly_coordinates/02_service_tray.stl
114.0 x 104.0 x 44.0

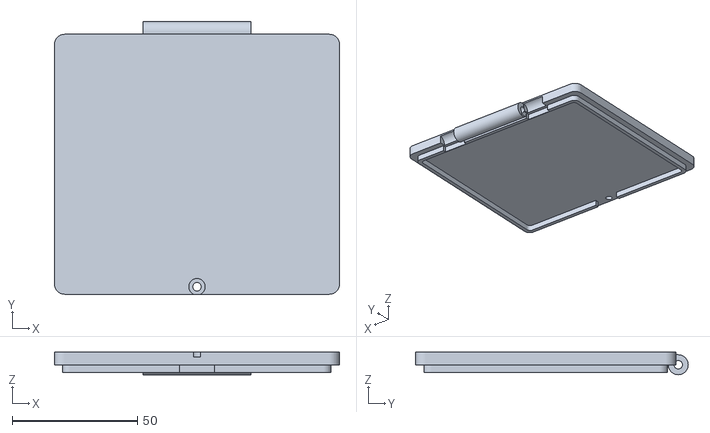
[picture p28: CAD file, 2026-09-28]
hardware information/AeroSense/STL/03_hinged_lid.stl
114.0 x 109.0 x 9.00

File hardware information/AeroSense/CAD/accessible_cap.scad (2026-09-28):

// Optional accessible two-piece gas cap. Replaces one operating part with two.
// Same nominal internal gas domain as baseline  when gasket is compressed to 0.6 mm.
include <model.scad>
part="split_lower";
module seal_ring(){difference(){box(22,19,.61,z=63.6);box(15,12,.8,z=63.5);}}
module locators(clearance=0,height=1.2){
 cyl(1.5+clearance,height,-12,8,64.2);
 cyl(1.5+clearance,height,10,-8,64.2);
}
module lower(){union(){difference(){intersection(){cap();box(70,70,64.2-50,z=50);}seal_ring();
 // Upper screw-ear bridges nest into these pockets; their underside seats at Z62.9.
 // 0.15 mm lateral clearance avoids an interference fit in brittle resin.
 for(y=[-19,19])box(8.3,8.3,1.5,0,sign(y)*15.5,62.9);
 }locators();}}
module upper(){difference(){union(){
 // 0.0001 mm CSG offset excludes coincident zero-thickness remnants of the plate.
 intersection(){cap();box(70,70,20,z=64.2001);}
 for(y=[-19,19]){cyl(4,2,0,y,62.9);box(8,8,2,0,sign(y)*15.5,62.9);}}
 locators(.15,1.4);
 for(y=[-19,19])cyl(1.7,4,0,y,62.8);
}}
if(part=="split_lower")lower();
if(part=="split_upper")upper();
if(part=="split_intersection")intersection(){lower();upper();}

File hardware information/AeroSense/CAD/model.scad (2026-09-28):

// AeroSense , mm. Original PCB datum retained. Nonbiological fit prototype.
// Canonical fallback CAD builder: OpenSCAD 2021.01 CGAL.
// Select part="cap", "body", "gas", "gas_open" or "plate"; print_pose=true only for body/cap.
part="well";
print_pose=false;
$fn=64;
hole_d=1.6; nx=4; ny=3; inlet_gap=1.5;
zin=64.2+inlet_gap; zroof=zin+3.3;
zliq=43+150/(4.7*3.4);
module box(w,d,h,x=0,y=0,z=0){translate([x-w/2,y-d/2,z])cube([w,d,h]);}
module cyl(r,h,x=0,y=0,z=0){translate([x,y,z])cylinder(h=h,r=r);}
module hcyl(r,h,x,y,z){translate([x,y,z])rotate([0,90,0])cylinder(h=h,r=r);}
module roundbox(w,d,h,r=4,z=0){
 union(){box(w-2*r,d,h,z=z);box(w,d-2*r,h,z=z);
 for(i=[-1,1])for(j=[-1,1])cyl(r,h,i*(w/2-r),j*(d/2-r),z);}
}
module plate(){difference(){box(14,11,1.2,z=63);
 for(i=[0:nx-1])for(j=[0:ny-1])cyl(hole_d/2,1.6,-4.8+i*9.6/(nx-1),-3.4+j*6.8/(ny-1),62.8);}}
module gas_open(){union(){box(14,11,zroof-61.8,z=60);
 for(sx=[-1,1])for(sy=[-1,1])box(4.7,3.4,60-zliq,sx*3.3,sy*2.65,zliq);
 hcyl(1.2,16.1,-23,0,zin);hcyl(1.2,16.1,6.9,0,61.5);}}
module gas(){difference(){gas_open();plate();}}
module cap(){difference(){
 union(){roundbox(32,26,zroof-58.9,2,58.9);
 difference(){roundbox(38,32,zroof-56.8,2,56.8);roundbox(34,28,zroof-55,1,56);}
 for(y=[-19,19]){cyl(4,4,0,y,58.9);box(8,8,4,0,sign(y)*15.5,58.9);}
 hcyl(1.7,8,-23,0,zin);hcyl(2,1,-21.5,0,zin);
 hcyl(1.7,8,15,0,61.5);hcyl(2,1,20.5,0,61.5);}
 gas();
 for(y=[-19,19]){cyl(1.7,7,0,y,58);cyl(4.3,2.9,0,y,56);}
}}
module body(){difference(){union(){import("inputs/body_input.stl",convexity=20);
 // Fill the old through-bores only inside the existing 3 mm side walls.
 for(s=[-1,1])box(3,6.4,6.4,s*55.5,0,58.8);}
 hcyl(3.1,10,-62,0,zin);hcyl(3.1,10,52,0,61.5);
}}
if(part=="cap")translate(print_pose?[23,23,-56.8]:[0,0,0])cap();
if(part=="body")translate(print_pose?[57,52,-3]:[0,0,0])body();
if(part=="gas")gas();
if(part=="gas_open")gas_open();
if(part=="plate")plate();

// Flat culture-contact floor. Uniform 0.5 mm bottom; PCB keepouts are retained below the well.
sx=1; sy=1;
module well_ne(){difference(){union(){
 box(5.8,4.5,15.8,3.3,2.65,42.5);
 box(6.5,5.2,1.5,3.65,3,56.8);}
 box(4.7,3.4,16,3.3,2.65,43);
}}
module well(){scale([sx,sy,1])well_ne();}
if(part=="well")well();
if(part=="well_section")intersection(){well();box(20,20,30,4,10+2.65,35);}
if(part=="cap_section")intersection(){cap();box(60,30,30,0,15,50);}

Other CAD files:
hardware information/AeroSense/CAD/assembly_coordinates/05_well_NW_CLEAR.stl
hardware information/AeroSense/STL/01_integrated_body.stl
hardware information/AeroSense/CAD/assembly_coordinates/05_well_NE_CLEAR.stl
hardware information/AeroSense/STL/05_well_SW_CLEAR.stl
hardware information/AeroSense/STL/05_well_NE_CLEAR.stl
hardware information/AeroSense/CAD/assembly_coordinates/05_well_SW_CLEAR.stl
hardware information/AeroSense/CAD/assembly_coordinates/01_integrated_body.stl
hardware information/AeroSense/STL/04_common_gas_optical_cap.stl
hardware information/AeroSense/CAD/assembly_coordinates/05_well_SE_CLEAR.stl
hardware information/AeroSense/STL/05_well_NW_CLEAR.stl
hardware information/AeroSense/CAD/assembly_coordinates/03_hinged_lid.stl
hardware information/AeroSense/STL/02_service_tray.stl
models/blender/AeroSense_Cinema_v7.blend
models/blender/AeroSense_Fly_v3.blend
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

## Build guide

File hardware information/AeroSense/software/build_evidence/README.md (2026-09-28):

Build evidence only. Default example credentials and BOARD_VALIDATED=false. Rebuild with private configuration before hardware use; do not publish credentials. Binaries were compiled, not flashed or electrically validated. Use PlatformIO upload/uploadfs to select correct flash offsets.
編譯證據；未燒錄或實板驗證。含公開範例金鑰且 LED 預設鎖定。使用前依手冊設定並重新編譯，不可公開私人金鑰。

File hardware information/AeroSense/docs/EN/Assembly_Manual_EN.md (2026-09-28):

# AeroSense assembly manual

Purpose: four separate liquid wells with a shared gas path, close to the four LEDs on the existing PCB and one collection PD. Nominal PCB: 100 x 90 mm; not yet fabricated. This is a complete engineering-prototype assembly procedure, not evidence of physical fit.

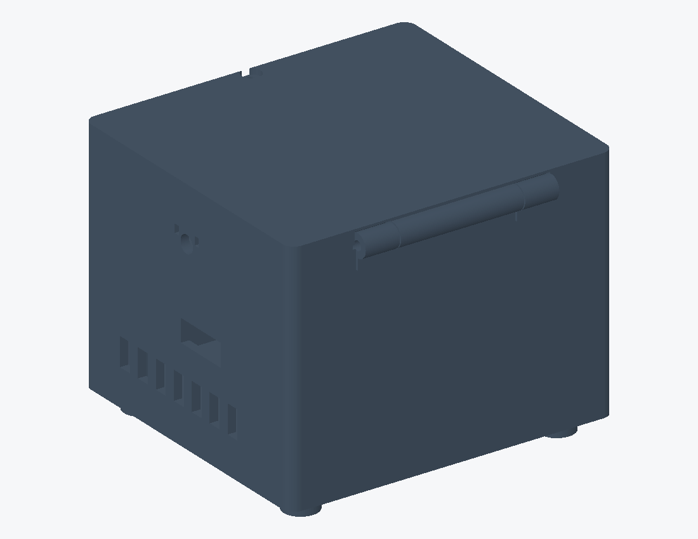
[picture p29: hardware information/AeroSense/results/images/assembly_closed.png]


Sequence: materials → vendor board dimensions → print coupons and dry parts → unpowered fitting → electronics → cell-free optical/gas tests → material and cell qualification. Stop at a failed gate; forcing parts or normalizing the signal does not resolve a physical defect.

STL/ contains eight operating parts. The two files in OPTION_accessible_cap replace part 04, giving nine operating prints. Do not stack both cap options. STLs are in mm, without supports; STL files do not encode units.

# 1. Materials, tools and printing

| Part | Resin / quantity |
| 01 integrated body | Rigid PC/GF-like Black x1 |
| 02 tray and PCB posts | Aqua 8K Gray x1 |
| 03 hinged outer lid | Rigid PC/GF-like Black x1 |
| 04 shared gas/optical cap | Rigid PC/GF-like Black x1 |
| 05 flat-bottom wells | Aqua Clear Plus x4, one per NE/NW/SW/SE |

Aqua Clear Plus is for fit/material testing, not a qualified HEK293T culture substrate. The black cap contacts sample gas and requires adsorption, residual and background testing. If the gray tray admits ambient light, print the same STL in Black without increasing part count.

Calibrate the Sonic Mighty Revo 16K with the actual resin batch; no guessed exposure time is specified. Trial the 0.15 mm side clearance, M3 nut pockets and 0.5 mm floor. Tilt large planes, drain well cavities and keep supports away from culture floors, seals and locating faces. Follow manufacturer washing, drying and curing instructions and measure after cure. Do not trap uncured resin in a cavity.

Tools: caliper, feeler gauge, M3/M4 hex tools, tweezers, scissors, appropriate PPE, multimeter and oscilloscope/logic analyzer; 0.8 mm silicone stock. Quantities and costs are in the separate BOM. Do not self-tap, hammer or repeatedly flex brittle resin.

# 2. Registration and pre-fabrication checks



This assembly view faces the optical side, with the D5 package center at (0,0). Nominal LED centers are (+/-3.3,+/-5.7); liquid-well centers are (+/-3.3,+/-2.65). The provisional PDF mapping is D1=SW, D2=SE, D3=NE, D4=NW. Confirm bottom-view mirroring rather than inferring wiring from left/right positions.

The Vishay drawing places the optical center 2.1 mm from the bottom of the 5 mm package, giving a 0.4 mm long-axis offset. Its world direction depends on rotation. The model uses (0,-0.4) and sweeps reversal; wells remain LED-registered. The 3 x 2.5 mm detector is an equal-area 7.5 mm2 proxy, not a supplied die outline.

Request populated-board STEP, thickness, hole coordinates/diameters, battery-holder height including cell, USB-C/SW1 access envelopes, LED emission-window coordinates and PD rotation. The nominal +/-45 and +/-40 mm holes and 1.6 mm thickness are not vendor-certified.

# 3. Fan, PCB and tray

1. Disconnect power and remove the battery. Remove supports, burrs and dust; check all eight parts for warp and trapped resin. Seat M3 nuts in their capture pockets without protruding into mating faces.

2. Place the 40 x 40 x 10 mm fan on tray 02, centered at (0,-12), with 32 mm hole pitch. Use four M4x20 screw/washer/nut sets. Intake through the base, flow under the PCB, exhaust through electronics openings. The fan is not connected to the well gas path.

3. Check underside clearance: allowable component height is 23 mm over the fan body and only 16 mm over its fasteners, both with a nominal 2 mm margin. If the battery holder enters the low-clearance area, resolve the layout/height before assembly; do not remove required PCB supports.

4. Place the PCB optical-side up on four posts. Secure with four M3x10 screws and 0.5 mm washers without contacting traces or bending the board. Check underside gaps with a feeler gauge. 5. The vendor must confirm the fan 5 V/GND connection and supply margin; LED gates are not power outputs. Insulate and strain-relieve wiring, then attach body to tray with another four M3x10 screws.

6. USB-C/SW1 cutouts remain nominal until a real board is available. Check full connector-body insertion/removal, full switch travel and cable clearance from optics. Record measurements in validation/fit_measurements.csv.

# 4. Optics, wells and seals

7. Locate the opaque PD soft ring: nominal 4 x 4 mm outside, 3 x 3.4 mm opening, 0.8 mm stock compressed to 0.6. Avoid bonds and terminals. The margin around the offset detector is small: confirm the window outline and rotation and measure clipping under positioning tolerances. This is not a qualified optical seal specification.

8. Install a filter no larger than 5.2 x 4.2 x 1 mm in its seat, Z41.1 to42.1. Retain only at dry corners, away from the aperture. A colored transparent sheet is not a qualified emission filter; verify rejection across the LED spectrum and green transmission over the incidence cone.

9. Slide NE/NW/SW/SE into their matching seats with flanges resting at Z56.8. These are rigid keyed cartridges, not flexible snap fits. Outer floors are Z42.5 and inner floors Z43, both planar, with 0.5 mm thickness. Cavities are 4.7 x 3.4 mm. Nominal 150 uL gives Z52.387; theoretical brim capacity is about244.5 uL. Verify volume with cell-free liquid.

10. Cut the common four-aperture gasket: outer14 x11.4 mm, opening centers (+/-3.3,+/-2.65), each4.7 x3.4 mm. Compress 0.8 mm stock to0.6 against cap hard stops. Do not cover openings or squeeze the gasket into liquid. The wells share gas and are not gas-isolated.

# 5. Inner cap, gas path and hinged lid

11. Integral cap04 contains a full horizontal plate:12 holes, diameter1.6 mm, thickness1.2 mm, Z63 to64.2. Inlet is on negative X above the plate at Z65.7; outlet is positive X below the plate at Z61.5. Both bores are2.4 mm; tails are3.4 mm with4.0 mm retaining ridges. Seat two M3x10 thumbscrews against hard stops without crushing wells.

The upper chamber of the integral cap is difficult to inspect, clean and cure; use it for dry/cell-free testing. For accessible cleaning surfaces, use the two-part OPTION cap: divider in the lower piece, roof in the upper, asymmetric locating pins, and an extra22 x19 mm gasket with15 x12 opening. Substitute two M3x12 thumbscrews; total prints9. Material and seal qualification still apply.

12. Fit one hydrophobic0.2 um gas filter to inlet and one to exhaust. Use externally controlled flow and pressure limiting. Never block exhaust, inject directly into liquid, or use the cooling fan to evacuate wells. Stop inlet flow before closing, keep filtered exhaust open to atmosphere, lower the cap slowly and alternate the screws; resume flow only after pressure returns to zero.

13. Pass the M3x75 pin through the hinge, add end washers and a nyloc nut to retain it without clamping the barrels. Close the front with one M3x12 thumbscrew. The outer lid is not an airtight piston; the gas seal is at the wells and inner cap.

# 6. Replacement, inspection and troubleshooting

Replace wells: stop acquisition → LEDs off → stop gas and verify zero pressure → open outer lid → release both cap screws → lift cap vertically while supporting hoses → lift wells by flanges → handle liquid under laboratory procedures → replace wells and clean sealing faces → repeat dark, baseline and reference calibration. Do not invert the filled instrument.

| Symptom | Action |
| Stuck well / loaded PCB | Measure shrinkage, burrs, flange and component heights; do not force. |
| ADC near0 or full scale | Check TIA, wiring, ambient light and filter before normalization. |
| Low flow / rising pressure | Stop gas; inspect wet filters, kinked tubing, blocked holes and reversed ports. |
| Signal jumps after closing | Check pressure pulse, seal displacement, light leaks and positioning repeatability. |
| Purple resin / high blank signal | Measure transmission and empty-well autofluorescence; polishing does not remove bulk absorption. |

Dry acceptance: no collision/bending, full nut engagement, removable wells, no hose pull and accessible connectors. Wet acceptance: no liquid reaches the PCB during dwell, tilt and lid cycles at defined fill; repeatable pressure/flow at operating temperature. CAD renders are not prototype photographs or evidence of success.

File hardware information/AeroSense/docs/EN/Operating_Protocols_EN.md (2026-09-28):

# Operating and validation protocols

This document defines an executable engineering sequence, data fields and provisional acceptance gates. Thresholds are initial project requirements, not established GCaMP6f/HEK293T biological safety standards. Pre-register them in the test plan and retain failures and raw data.

| Stage | Inputs / records |
| A Electronics | Supply, D1-D4 frequency/current, ADC waveform and raw codes |
| B Optical blanks | Dark, empty well, medium, GCaMP-negative cells, fluorescent standard |
| C Gas/mechanics | Flow/pressure, leaks, closure pulse,20 replacement cycles |
| D Cells/reference | Batch, density, receptor, reference challenge, viability and pH |
| E Analysis | Raw I/Q, mixing matrix, normalization and independent-batch validation |

Log operator ID, date, device ID, firmware/CAD hashes, resin lot/cure, well and cell batch, fill volume, temperature, humidity, CO2/pH, standard gas concentration with units, flow, duty and filter IDs. Exclude unitless concentration records from training.

# A. PCB bring-up and four-frequency sampling

1. Ask the vendor to verify power routing, battery polarity, SW1, digital/analog3.3 V and2.5 V reference. Start with a current-limited supply and record voltage/current/heating with idle, Wi-Fi, each LED and fan. The candidate fan adds up to157 mA at5 V (0.785 W); supply margin is not established.

2. Scope GPIO25/26/27/32 and MOSFET drains for D1-D4. Use41/67/89/113 Hz and initially low-duty short tests; measure LED current and optical power. Duty changes pulse fraction, not regulated current amplitude. Verify LEDs off at stop, error, reset and power-down.

3. ADS8866 uses GPIO33 CONVST,18 SCLK,19 DOUT; DIN is pulled high. Check conversion-high time of at least8.8 us before reading. Implementation waits10 us, then SPI mode0 at2 MHz,16-bit MSB first. Verify offset, midscale and gain using a suitable known input and measured VREF; never apply an over-range signal.

4. Each2 s block has8000 samples at4 kS/s. Provisional gates: no lost samples, no rail samples, maximum interval error≤50 us; otherwise invalid. This timing gate does not prove accuracy: measure synchronous crosstalk and amplitude error as well. Enable BOARD_VALIDATED only after checking actual waveforms.

5. Use a stable controllable optical source at≥5 intensities and10 blocks each for linearity, dark noise, repeatability and channel leakage. Initial targets: midrange CV≤5%, fit residual≤5%, no saturation. Detection limits require blank distributions and replicated low-concentration measurements.

# B. Optical calibration and purple resin

Print0.5/1/2 mm coupons with identical cure, measure transmission over the LED and GCaMP emission bands, and separately assess scattering and blank fluorescence. Use matched blanks/exposure and≥3 coupons; report mean, SD, thickness and instrument calibration. Beer-Lambert estimates bulk absorption only after accounting for reflection/scattering.

Purple tint may reflect bulk absorption or dye/photoinitiator. Polishing addresses surface scatter. A single scale factor cannot correct background or spectral attenuation that changes with lot, cure or soaking. Fast path: cell-free optical blanks first. If they fail, use qualified optical windows/culture vessels and re-fit the mechanics.

Mixing matrix: hold LED/electronics settings constant; place the same stable fluorescent standard in one well at a time, with matched blanks in the others. Record complex I/Q at all four frequencies,≥5 replicates per well. Rows of M are LED frequencies, columns are wells: y=Mx+b. Subtract complex background before inversion. Attempt inversion only under matched conditions and condition number<30, a provisional threshold requiring uncertainty propagation.

Synchronous signals from GCaMP-negative cells or medium may arise from blue leakage or resin. DLIA does not remove LED-synchronous background. Verify the filter over actual angles/spectra; catalog optical density is not the assembled-system leakage ratio.

# C. Gas, pressure and assembly stability

With cell-free liquid, compare the no-plate control and selected plate at an initial0.25/0.5/1 mL/min sweep. This is a test range, not demonstrated cell tolerance. Install both filters, tubing and cap. Record inlet/outlet flow, differential pressure, closure pulse, mass loss and liquid disturbance.

Hole speed scales approximately asQ/A_open; reducing area at fixed flow raises jet speed. Filters are excluded from CFD and may dominate pressure loss. With blocked ports, closure gives ΔP≈P_atm ΔV/V: a1% compression is about1 kPa, far above the modeled chamber loss near0.01 Pa. Keep filtered exhaust open and close slowly.

Define leak acceptance from exposure requirements after measuring flow-meter uncertainty. An inlet/outlet mismatch may reflect leakage, instrument error or transients. Stop for wet/blocked exhaust filters or abnormal pressure. This enclosure is not a pressure vessel.

Assembly stability:20 well/lid replacement cycles with the same blank or stable fluorescent standard, fill and settings. Record channels, leaks, positioning, damage and time. Start with signal CV≤5% and compare against drift without disassembly. Report failures; a plate need not improve uniformity.

# D. Cells and reference challenges

The system uses HEK293T, not bacteria. Culture, identity, mycoplasma checks, handling and waste follow the laboratory procedures for that cell line. Filters and gaskets are not a biosafety cabinet, and optical qualification is not cell compatibility.

First compare extract exposure and direct contact against a commercial culture-vessel control, matching batch, density, medium, receptor/GCaMP expression and observation time. Use≥3 independent batches. Assess morphology, attachment, viability, pH, baseline and reference response, not brightness alone.

The device has no heater, cell-temperature or CO2 sensor. Even short exposure outside culture conditions may alter pH and response. Record actual liquid temperature, buffer, CO2, humidity and evaporation. Continuous culture requires external environmental control or additional design; a cooling fan is not culture control.

Prefer a traceable, stable odor reference known to activate the specific receptor, with matched carrier gas as blank. Select a repeatable nonsaturated concentration from dose-response data. Calcium-active reagents may test downstream response but are not receptor-specific odor controls and may alter later measurements. No universal dose is invented for an unspecified receptor.

Per batch: blank → baseline → reference → recovery check → randomized samples/blanks → ending reference. If reference causes irreversible drift, use a separate reference well/batch rather than repeatedly stimulating the same well. Shared-gas wells are not unexposed gas controls.

# E. Normalization, performance and model validation

Correct instrument gain, phase and background before biological ΔF/F0=(F-F0)/F0. The UI subtracts complex dark signal per frequency before taking amplitude. Use≥5 valid blocks each for dark, baseline and reference. Reject a near-noise baseline. Reference normalization isR=(F-F0)/(Fref-F0); do not report R when the denominator is below5 times dark-noise estimate.

Excitation differs between LEDs; wells need not share a scale. Without measured M, the UI displays normalized LED channels rather than claiming unmixed cellular wells. Calibration does not repair saturation, nonlinearity, changing spectra or inactive receptors.

Performance testing includes blanks, rise/recovery time, range/dose response, within/between-day repeatability, cross-odor responses, temperature/humidity interference, carryover/cleaning, bleaching/phototoxicity and assembly cycling. Biological n is independent batch; windows from one batch are technical replicates. Report raw data, exclusion reasons and intervals, not selected attractive traces.

Split the NN dataset by cell batch/day/device; never place adjacent windows from one run across train/test. Fit feature scaling on training only. The supplied small MLP trains and predicts, but no labeled biological dataset is available, so no fabricated odor model or accuracy is supplied. Reserve prospective testing and report confusion, per-class recall, unknown/no-response cases and failures.

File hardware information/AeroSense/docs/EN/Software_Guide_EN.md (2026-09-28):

# Phone UI and ESP32 quick start

Two paths are provided: (1) phone connects directly to the ESP32-hosted page; (2) ESP32 uploads/polls a server and the phone opens that server. Both use the same UI and result schema. The demo server uses clearly marked synthetic data and never silently substitutes for hardware.

Quick trial: with Python3.12, open a terminal in software/server and run python server.py --demo. Open http://127.0.0.1:8765 on the computer, enter API key local-demo-key, connect, start and stop. Check the DEMO label and four channels. No PCB or paid cloud is needed.

Phone trial: connect phone/computer to trusted Wi-Fi, set different AEROSENSE_UI_KEY and AEROSENSE_DEVICE_KEY values, then start with --host0.0.0.0. Open the computer LAN IP:8765 on the phone. Default binding is loopback. The package does not publish an Internet service or supply cloud credentials.

UI features: bilingual switch, finite block schedule, duty, dark/single/all LED selection, QC, calibration capture, ΔF/F0/reference normalization, JSON/CSV export and direct-device raw ADC download. Missing battery/cell-temperature sensors are shown as unavailable.

# Flashing and first hardware connection

1. Install PlatformIO. platformio.ini pins espressif32@6.10.0 and ArduinoJson@6.21.5. Extract to a short ASCII path, e.g.C:/AeroSense, because long Windows paths may prevent compiler subprocesses. Run pio run to compile and pio run -t buildfs for the UI filesystem.

2. Copy src/config.example.h to src/aerosense_config.h and set Wi-Fi, AP password and API key. Do not publish the populated file. BOARD_VALIDATED defaults false, allowing dark acquisition only. Set true and rebuild after supply, ADC and LED waveform checks.

3. J2 USB-C is not established as a USB-UART bridge. Use a3.3 V logic USB-UART at J3 with common ground and crossed TX/RX with schematic J3 pin1=3V3_DIG, pin2=TXD0(GPIO1), pin3=RXD0(GPIO3), pin4=GND; verify connector pin1 orientation and leave adapter VCC disconnected when the main supply is on. Never use5 V UART. Hold GPIO0 low with SW3 and reset with SW2 for download mode; run pio run -t upload and pio run -t uploadfs, then reset normally.

4. Connect phone to the AeroSense AP, open http://192.168.4.1 and enter your API key; alternatively use the ESP32 LAN address after joining lab Wi-Fi. AP access is not Internet remote access. Begin with dark blocks and raw ADC checks.

The source was actually compiled. Default firmware contains no personal network credentials and has not been flashed or exercised on the board. Build success verifies compilation/linking/size, not timing under Wi-Fi load.

# Communication, retention and cloud

| Endpoint | Behavior |
| GET /api/status | Mode, state, latest block and QC |
| POST /api/command | start/stop; blocks1-60, intervalSec3-300, duty1-50, ledMask0-15 |
| GET /api/raw.csv | Direct ESP32 latest raw block; rejected while sampling |
| POST /api/device/result | Device-key upload, ID deduplication, SQLite storage |
| GET /api/device/poll | Device polls expiring command |
| POST /api/device/ack | Execution/rejection acknowledgment |
| POST /api/predict | Research inference; explicit rejection without a model |

Use X-Aero-Key for UI and a separate X-Device-Key for the device. Internet deployment requires an HTTPS reverse proxy and a CA certificate on ESP32; no setInsecure is used. ALLOW_LAN_HTTP is for private LAN tests only. Do not expose plaintext control publicly. server.py is a research service requiring deployment, backups and access management for production.

ESP32 holds the latest raw block and up to8 pending summaries in RAM, stopping new acquisition when the queue fills. Reboot loses unsaved data. Server stores summaries; raw ADC must be downloaded per block or persistent storage added. UI retains the latest1000 received blocks and does not backfill on reload; use server/api/export.json for full stored history.

Stop is a network command, not a hardwired emergency stop. Each exposure is bounded to2 s even offline, but an already programmed finite local session can continue. Use SW1 for immediate power removal. UI does not actuate gas valves, temperature or fan speed because those control/sensing connections are absent.

# Calibration operation and analysis reproduction

Acquire five dark blocks with LEDs off, adding each completed unique ID to Dark. Use all four LEDs and a matched blank for five Baseline blocks. Apply the reference and capture≥5 blocks at predeclared times, adding each to Reference. Clear/repeat calibration after duty, cells or wells change.

Calibration is stored locally in this browser; the key stays in page memory. Exported JSON contains I/Q, amplitudes, calibration records and normalization; CSV is a channel-amplitude table. Keep private experiment records and credentials out of the public wiki package.

software/analysis/dlia.py provides timestamp-aware joint least squares, complex unmixing and48 synthetic sweeps. Firmware uses fixed-window I/Q; their differences are documented. Run python dlia.py --sweep to regenerate CSV, figure and validation JSON.

NN training CSV columns:sample_id,group,label,D1,D2,D3,D4, with predefined ΔF/F0 features. Run python odor_model.py train data.csv --holdout batch3 --out trained_model. Require≥3 independent groups; holdout does not participate in scaling/tuning. Set AEROSENSE_MODEL to model.json to enable server inference, still labeled research-only.

Quick reproduction: from package root run python reproduce.py --plots to redraw stored numerical results; --optics reruns optics, --flow reruns27 plate CFD cases plus the no-plate control (NumPy is slower; C# accelerator optional), --video makes MP4. Parameters and seeds are retained.

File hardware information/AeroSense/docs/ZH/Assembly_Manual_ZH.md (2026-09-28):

# AeroSense 組裝手冊

用途：四個液體獨立、气路共用的平底井，靠近原PCB四顆LED，一顆PD收光。PCB名目100×90 mm；原板尚未製造。本手冊是一份完整的工程原型組裝流程，並未把名目CAD配合當成實板驗證。



先做順序：閱讀材料表 → 量測廠商板件資料 → 列印配合試片與乾式零件 → 不通電試裝 → 電子檢查 → 無細胞光學／氣路測試 → 材料與細胞驗證。任何步驟不合格，就停在該步，不用硬壓零件或靠normalize掩蓋問題。

STL/根目錄共8個工作件。OPTION_accessible_cap中兩件會替代04內蓋，使整機變9件；不是再把兩個蓋子疊上去。所有零件以mm輸出、無支撐，STL本身不攜帶單位。

# 1. 材料、工具與列印

| 零件 | 樹脂／數量 |
| 01一體主殼 | Rigid PC/GF-like Black ×1 |
| 02底座與PCB柱 | Aqua 8K Gray ×1 |
| 03鉸鏈外蓋 | Rigid PC/GF-like Black ×1 |
| 04氣路遮光內蓋 | Rigid PC/GF-like Black ×1 |
| 05四個平底well | Aqua Clear Plus ×4，NE/NW/SW/SE各1 |

Aqua Clear Plus為配合與材料試驗用，不是已驗證的HEK293T培養材。黑樹脂內蓋亦接觸樣本氣體，須測氣味吸附、殘留與背景。Gray底座若透外光，使用同一STL改印Black，不增加件數。

用Sonic Mighty Revo 16K與實際樹脂批號校正，不猜曝光秒數。先做0.15 mm單邊滑配、M3螺帽槽及0.5 mm底厚試片。大平面傾斜列印；井腔朝可排液方向，支撐避開液面接觸底、密封面及定位面。依原廠清洗、乾燥、固化流程，測固化後尺寸。未清除的液態樹脂不能封在內腔。

工具：游標卡尺、塞尺、M3/M4對應六角匙、鑷子、小剪刀、適當防護、萬用表、示波器／邏輯分析儀；軟矽膠片0.8 mm。完整數量與單價在獨立BOM工作簿。樹脂不可直接攻牙、硬敲或反覆彎折卡扣。

# 2. 座標、對位與送製前檢查



本圖採光學面朝上的組裝視角，D5封裝中心為(0,0)。LED中心名目(±3.3,±5.7)，液體井中心(±3.3,±2.65)。D1=SW、D2=SE、D3=NE、D4=NW是PDF讀圖的暫定對應；須確認BOTTOM圖是否鏡像，不能只看左右猜接線。

Vishay圖面光學中心距5 mm封裝底邊2.1 mm，因此沿長軸偏0.4 mm；方向取決於元件旋轉。模擬暫用(0,-0.4)，並掃描反向。四井仍依LED定位。實際die形狀沒有被完整提供，模擬3×2.5 mm僅是7.5 mm²等面積近似。

向廠商索取：含元件STEP、板厚、四孔座標與孔徑、底面电池座含電池高度、USB-C與SW1插拔包络、LED出光窗與PD旋轉。名目孔位±45/±40 mm、板厚1.6 mm不是廠商認證尺寸。

# 3. 風扇、PCB與底座

1. 斷電並移除電池。清除支撐、毛邊、粉屑，確認八件沒有翹曲或封閉樹脂囊。將M3螺帽放入對應捕捉槽，應平貼且不能突出裝配面。

2. 將40×40×10 mm風扇放在02底座，中心(0,-12)，四孔距32 mm。用4組M4×20螺絲／墊片／螺帽固定。氣流經底座吸入，流過PCB下方，再從電子艙開口排出。風扇不連通well氣路。

3. 確認風扇與固定件不碰板底元件：風扇本體上方允許23 mm元件高度，固定件上方僅16 mm，兩者都已預留2 mm名目間隙。電池座若進入較低區域，必須先改座位／高度，不能剪掉必要的PCB固定柱。

4. PCB光學面向上，放在四柱上。4顆M3×10螺絲配0.5 mm墊片固定，不壓電路、不使PCB彎曲。用塞尺確認板底避空。5. 接風扇5V與GND需廠商確認接點及供電餘量，不能把LED gate當供電。做好絕緣與拉力固定，再用另外4顆M3×10把主殼與底座固定。

6. 實板尚未到手，USB-C／SW1開口只能作名目試裝。應讓插頭外殼完全進出，開關全行程不摩擦，線材不掃到光學部件。請把實測尺寸填入validation/fit_measurements.csv。

# 4. 光學、井與密封

7. 將PD不透光軟圈定位於封裝上，名目外4×4、內3×3.4 mm，原厚0.8壓至0.6。不可碰bond／元件端子；偏心感光區到圈邊的裕量很小，必須向廠商確認window輪廓與旋轉，再測位置公差下遮擋比例。此尺寸不是已確認的光學密封規格。

8. 濾片最大5.2×4.2×1 mm，放入座內，Z41.1至42.1。只在乾區角落固定，不把膠伸入光孔。透明色片不等於合格發射濾片；需確認藍光完整波段阻擋與實際入射角下綠光透過率。

9. NE/NW/SW/SE各放入對應滑槽，讓凸緣落在Z56.8支承面。這是剛性卡匣滑入定位，不是彈性卡扣。四井外底Z42.5、內底Z43，均為平面，底厚0.5 mm；井腔4.7×3.4 mm。名目150 µL時液面Z52.387，理論滿杯約244.5 µL。先用無細胞液體量測實際容量。

10. 四孔井密封片外14×11.4 mm，孔中心(±3.3,±2.65)，每孔4.7×3.4 mm。0.8 mm片壓至0.6，由內蓋硬止擋限制壓缩。不要遮住井口，也不要讓密封片擠入液體。四井氣體共用，不宣稱氣相隔離。

# 5. 內蓋、氣路與可開闔外蓋

11. 一體04內蓋包含完整水平孔板：12孔、直徑1.6 mm、厚1.2 mm，板Z63至64.2。孔板上方由負X側進氣，管軸Z65.7；下方由正X側排氣，管軸Z61.5。兩端內徑2.4 mm，接尾外徑3.4、凸環4.0 mm。以2顆M3×10手轉螺絲鎖到硬止擋，不靠大扭力壓井。

一體內蓋上層難以目視清洗和固化，只作乾式／無細胞試驗。需要可接近的清洗面時，改用OPTION兩件內蓋：下件內建孔板，上件是屋頂，非對稱定位柱避免反放；增裁22×19、內孔15×12 mm密封圈。改2顆M3×12手轉螺絲；總工作列印件9。仍需材質與密封試驗。

12. 進、排氣各接一個疏水0.2 µm氣體濾器。外部供氣須可控流量與限壓。不要堵住排氣、把氣體直接打入液體，或用風扇抽取培養井。關內蓋前先停止供氣，保持排氣經濾器通大氣，緩慢落蓋並對角輕鎖；確認壓力回到零再供氣。

13. M3×75直桿穿過外蓋鉸鏈，加兩端墊片與尼龍防鬆螺帽，只限制滑出，不夾死轉軸。前端用1顆M3×12手轉螺絲閉合。外蓋故意不做氣密活塞；真正的氣路密封在well與內蓋。

# 6. 更換、初驗與故障排除

更換井：停止量測 → LEDs關閉 → 停供氣且確認無壓 → 打開外蓋 → 鬆兩顆內蓋螺絲 → 垂直提蓋並托住軟管 → 用凸緣提起各井 → 依實驗室流程處理液體 → 換井及清潔密封面 → 重新暗訊號、基線和標準品校正。不能在含液狀態翻轉整機。

| 現象 | 處理 |
| well卡住／PCB受力 | 量收縮、毛邊、凸緣及板上元件高度；不硬壓。 |
| ADC貼近0或滿刻度 | 查TIA、接線、外光和濾片；不可先normalize。 |
| 氣流低／壓力升高 | 停氣；查濾器濕潤、管折、堵孔、反接。 |
| 開關蓋後訊號跳動 | 查壓力脈衝、密封位移、外光及井定位重複性。 |
| 紫色透明井背景高 | 測光譜與空井自發螢光；拋光不能去除材料體吸收。 |

乾式驗收：無碰件、無彎板、螺帽全咬合、井可手動取放、開蓋不拉管、連接器可插拔。含液驗收：固定容量下靜置、傾斜與開蓋循環皆無液體接觸PCB，使用溫度下壓力與流量可重複。未完成這些記錄前，不把CAD渲染當成實物照片或成功證據。

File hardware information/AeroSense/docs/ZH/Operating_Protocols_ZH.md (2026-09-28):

# 操作與驗證流程

本文件提供可執行的工程測試順序、資料欄位與暫定放行門檻。門檻是本專案的起始工程要求，不是公認GCaMP6f／HEK293T生物安全標準。先在測試計畫中登錄，失敗也保留原始資料。

| 階段 | 輸入／產物 |
| A 電子 | 電源、D1-D4頻率／電流、ADC波形、原始碼值 |
| B 空白光學 | 暗、空井、培養液、無GCaMP細胞、螢光標準 |
| C 氣路與機構 | 流量／壓差、漏液、關蓋壓力脈衝、20次更換 |
| D 細胞與標準品 | 細胞批次、密度、受體、參考刺激、存活與pH |
| E 分析 | 原始I/Q、校正矩陣、正規化、獨立批次驗證 |

每次記錄：操作者匿名代碼、日期、device ID、firmware與CAD檔案雜湊、樹脂批次及固化紀錄、井別與細胞批次、填充量、溫度、濕度、CO2／pH、標準氣體濃度與單位、流量、曝光duty、濾器／濾片型號。缺少單位的濃度資料不進模型訓練。

# A. PCB上電與四頻取樣

1. 由廠商先確認電源路徑、電池極性、SW1、3.3V數位／類比及2.5V參考。以限流電源開始，記錄空載、Wi-Fi、每顆LED和風扇的電壓／電流／溫升。風扇候選最大另需157 mA@5V（0.785 W）；不能假設原設計有此餘量。

2. 示波器看GPIO25/26/27/32及MOSFET drain；對應D1-D4。固定41/67/89/113 Hz，先低duty短時測試，量實際LED電流與光功率。Duty改變的是脈衝比例，不是恆流振幅。確認關機、停止、錯誤與重啟時全部關燈。

3. ADS8866：GPIO33 CONVST、18 SCLK、19 DOUT，DIN由硬體拉高。核對CONVST高至少8.8 µs後才讀；實作等待10 µs，SPI mode0、2 MHz、16位MSB first。以已知輸入確認零點、中量程與增益，VREF實測代入。不可直接把高電壓訊號接上ADC。

4. 每組2秒、4 kS/s共8000點。暫定：不漏點、無rail samples、取樣間隔最大誤差≤50 µs；不合格組標invalid。這個門檻不是準確度證明，須再量測同步串擾及振幅誤差。示波器確認程式時序後，才允許BOARD_VALIDATED=true。

5. 用稳定可控光源做至少5個強度、每級10組，量線性、暗噪聲、重复性与LED切換串擾。提議起始目標：中量程重複CV≤5%、擬合殘差≤5%；全量程不飽和。實際檢出限需由空白分布與低濃度重複實驗推定。

# B. 光學校正與紫色樹脂

同一批固化試片做0.5／1／2 mm厚度，測完整LED發射範圍與GCaMP發射範圍的穿透光譜，另量散射與空白螢光。使用空白參考與相同曝光，至少3件試片，報平均、標準差、厚度及儀器校正。Beer-Lambert可估體吸收，但表面反射和散射需分辨。

紫色可能來自吸收或染料／光引發劑，拋光只改善表面散射。若高背景或波段衰減隨批次、固化、浸泡時間改變，不能用單一倍率修正。快速路徑：先用透明井做無細胞光學空白；不合格則停止採用該樹脂作正式光窗，改用已驗證材料的光窗／培養容器，機構需重新配合。

光學串擾矩陣：固定LED與電子設定，每次只在一個井放同一穩定螢光標準，其他三井放匹配空白；記錄四頻複數I/Q，四個井各重複至少5次。所得M的列為LED頻率、欄為well，使用y=Mx+b。先扣除複數背景b，再求x；量測條件一致且矩陣條件數<30才嘗試反解。30是暫定工程門檻，需報誤差傳播。

GCaMP陰性細胞／培養液的同步訊號可來自漏藍光或樹脂，DLIA不會消除與LED同頻的背景。濾片須經實測入射角與光譜證明；採購OD規格不是本機漏光比例。

# C. 氣路、壓力與組裝穩定

在無細胞液體下測無孔板對照與選定孔板，建議掃0.25／0.5／1 mL/min。這是初始量測範圍，不是已證實細胞可耐受流量。兩端濾器、接管與內蓋需同時在位。記錄入口／出口流量、兩端壓差、關蓋瞬時壓力、質量變化及液面擾動。

孔板的孔速約Q/A_open；在定流量下減少開孔面積會增加孔速。模擬不含濾器，實際濾器可能主導壓降。閉蓋時若所有氣路堵死，ΔP約P_atm×ΔV/V：即使只壓縮1%氣體也約1 kPa，遠大於此模型約0.01 Pa的內艙流阻。保持過濾排氣暢通、低速閉蓋比「把所有地方封死」重要。

密封目標需依暴露規格制定：先量儀器本身流量誤差，再評估入口與出口差值；差值不能只用單一數值判斷漏氣，也可能是量測誤差或暫態。排氣濾器一旦濕潤、堵塞或壓力异常，立即停止。不能用這個殼當壓力容器。

組裝穩定試驗：同一空白或螢光標準，20次取放井／開關蓋，每次相同液量与設定，記錄四通道、漏液、定位、零件損壞与所需時間。先以訊號CV≤5%作起始目標，並與未拆裝的時間漂移對照分開。孔板不一定改善均匀度；必須報失敗結果。

# D. 細胞與參考刺激

使用HEK293T，並非細菌。培養、來源驗證、黴漿菌、廢棄及操作應遵循所在地實驗室對該細胞株的核准流程。外殼濾器與密封片不等於生物安全櫃，樹脂光學合格也不等於細胞相容。

先做材料浸出液與直接接觸對照：商用培養容器作基準，匹配细胞批次、密度、培養液、受體／GCaMP表達與觀察時間；至少3個獨立細胞批次。記錄形態、貼附、存活、pH、基線及參考刺激反應，不能只比較總亮度。

目前機構没有加熱、細胞溫度或CO2感測器。短時離開培養環境也可能改變pH與反應。記錄實際液體溫度、緩衝系統、CO2、濕度與蒸發；若需要持續培養，需外部環控或新增設計，風扇不能取代培養控制。

參考品優先選已確認能啟動該受體、穩定可取得、濃度可追溯的氣味標準；空白用同一載氣。濃度先由劑量反應實驗選在可重複且未飽和的範圍。鈣離子相關藥劑可檢查下游反應，但不等於受體對氣味的陽性對照；不可假定每次使用不影響後續細胞。此處不捏造尚未指定受體的通用濃度或藥劑配方。

建議每批：空白 → 基線 → 標準品 → 回復確認 → 隨機化樣本與空白 → 結尾標準品。若標準品造成不可逆漂移，改用獨立參考井／平行批次，而不是強制重複刺激同一井。四井共享氣體，不能把其中一井稱為「未暴露氣體對照」。

# E. Normalize、效能與模型驗證

儀器層先校正gain、phase和背景，生物層才算ΔF/F0=(F-F0)/F0。介面先逐頻率扣除複數暗訊號，再取振幅。基線F0與標準刺激各至少5個有效組；F0接近噪聲時拒絕除法。標準品正規化R=(F-F0)/(Fref-F0)，分母不足5倍暗訊號噪聲時不輸出R。

每個頻率的LED直接激發量可能不同，四井不能互相當成相同尺度。若沒有實測M，介面顯示的是LED通道正規化，不是假裝已解出獨立細胞井。校正不能補救飽和、非線性、材料光譜变化或受體失活。

效能測試至少包含：空白分布、反應時間與回復、量程／劑量反應、日內及跨日重複性、交叉氣味、濕度／溫度干擾、記憶效應與清洗、光漂白与光毒、裝配循環。以實驗批次為生物n；同一批的多個時間窗是技術重複。報原始資料、排除理由、平均與區間，不只挑漂亮曲線。

NN以cell batch／day／device分組切訓練與測試，不能把同一run的相鄰時間窗拆到兩邊。特徵正規化只用訓練集。交付的小型MLP可訓練和推論，但沒有實驗標籤資料，因此不附虛構氣味辨識模型或準確率。需留前瞻測試集，報混淆矩陣、各類召回、無反應／未知類及失敗模式。

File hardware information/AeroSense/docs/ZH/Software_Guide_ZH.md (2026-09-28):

# 手機介面與ESP32上手

提供兩條路徑：①手機與ESP32直接連線，使用ESP32內建網頁；②ESP32主動向伺服器上傳／領取指令，手機開伺服器網頁。兩者共用相同UI與資料結構。示範伺服器使用合成數據，標示DEMO，不會自動切成實機數據。

最快先試：安裝Python 3.12，開software/server資料夾終端機，執行 python server.py --demo。電腦開http://127.0.0.1:8765，API key填local-demo-key。按連線、開始排程，確認DEMO標籤、四路數據與停止。這不需要PCB或付費雲端。

手機試用：電腦與手機接同一可信Wi-Fi，設定AEROSENSE_UI_KEY與AEROSENSE_DEVICE_KEY兩個不同密鑰，再用 --host 0.0.0.0啟動；手機開電腦的區網IP:8765。伺服器預設只綁本機；此套件不替你公開網際網路服務，也不含雲端帳號。

介面：中英文切換、有限組數排程、duty、全關／單LED／四LED、結果品質、校正收集、ΔF/F0與參考值、JSON／CSV匯出、直連時原始ADC下載。無電池／細胞溫度感測器時顯示未配置，不捏造數據。

# 燒錄與首次實機連線

1. 安裝PlatformIO。software/firmware內platformio.ini固定espressif32@6.10.0、ArduinoJson@6.21.5。用短英文路徑解壓（例如C:/AeroSense），Windows長路徑可能使編譯器找不到子程序。執行pio run編譯；pio run -t buildfs建立UI檔案系統。

2. 複製src/config.example.h成src/aerosense_config.h，填Wi-Fi、AP密碼、API key。不要把填好的檔案傳到wiki。BOARD_VALIDATED預設false，只允許全關LED的暗取樣；完成電源、ADC與示波器LED檢查後才改true重新編譯。

3. J2 USB-C沒有證據是USB轉UART。使用3.3V邏輯USB-UART與J3，共地、交叉TX/RX，原理圖J3：1=3V3_DIG、2=TXD0(GPIO1)、3=RXD0(GPIO3)、4=GND；以接頭pin1標記確認方向。主電源供電時不接UART VCC；禁止接5V UART。以SW3將GPIO0拉低並用SW2 reset進下載模式，執行pio run -t upload，接著pio run -t uploadfs。再reset正常開機。

4. 手機連AeroSense AP，開http://192.168.4.1，用設定的API key登入。或等ESP32連入實驗室Wi-Fi後以其IP連線。AP模式本身不是跨網際網路遠端。先做暗組與ADC原始碼值檢查，再做有光量測。

原始碼已實際編譯；預設韌體不包含你的網路密鑰，亦未燒錄或測過實板。編譯成功證明語法／連結與容量可接受，不能證明ADC時序在Wi-Fi負載下符合要求。

# 通訊、資料保存與雲端

| 項目 | 行為 |
| GET /api/status | 模式、狀態、最新量測及品質 |
| POST /api/command | start/stop；blocks1-60、intervalSec3-300、duty1-50、ledMask0-15 |
| GET /api/raw.csv | 直連ESP32下載最近組；取樣時拒絕 |
| POST /api/device/result | 設備密鑰上傳，result ID去重，SQLite保存 |
| GET /api/device/poll | 設備主動領取有限有效期指令 |
| POST /api/device/ack | 回覆執行／拒絕原因 |
| POST /api/predict | 伺服器研究模型推論；無模型明確拒絕 |

區網用X-Aero-Key，設備用不同X-Device-Key。跨網路部署必須HTTPS反向代理，ESP32指定CA憑證，不使用setInsecure。ALLOW_LAN_HTTP只能在私有區網測試時開；不要把明文控制端點直接暴露公網。server.py是研究用服務，正式多人服務需自行部署、備份和權限管理。

ESP32以RAM保存最新原始組與最多8組待上傳摘要，佇列滿就停止後續量測，重開機會丟失未保存資料。雲端保存摘要，完整ADC需每組直連下載或擴充持久儲存。本UI保留最近1000組瀏覽器收到的摘要；開新頁不會自動補齊過往歷史，完整歷史用伺服器/api/export.json。

停止是網路指令，不是硬接線緊急停止。即使失聯，每組曝光最多2秒，但已設定的有限本地排程可繼續。需要立即斷電用SW1。UI不控制氣閥、溫度或風扇轉速，因PCB沒有對應驅動／感測連線。

# 校正操作與分析重現

先全關LED取得暗訊號5組，每一組完成後按「加入暗訊號」，同一id不能重複加入。換成四LED、匹配空白取得基線5組，每組按「加入基線」。加入標準刺激後依固定時間點取得至少5組，按「加入標準刺激」。改duty、細胞或井後清除校正重做。

校正在此瀏覽器本機保存，密鑰只在本頁記憶體中。匯出的JSON包含原始I/Q、振幅、校正紀錄和正規化結果；CSV是LED振幅簡表。不要把含細胞實驗記錄或網路密鑰混進公開wiki下載包。

software/analysis/dlia.py提供timestamp-aware joint least squares、複數串擾反解與48組合成數據掃描；韌體使用固定窗I/Q，其差異已列在分析報告。python dlia.py --sweep可重新生成CSV、圖及驗證JSON。

NN訓練CSV欄位：sample_id,group,label,D1,D2,D3,D4，D欄為事先定義的ΔF/F0特徵。執行python odor_model.py train data.csv --holdout batch3 --out trained_model。至少3個獨立group；測試group不得參與scaling或調參。用AEROSENSE_MODEL指向model.json啟用伺服器推論；回傳仍標示研究模型。

快速重現：在套件根目錄執行python reproduce.py --plots重畫既有數值；--optics重新計算光學，--flow重新計算27組孔板CFD加無孔板對照（NumPy較慢，可先編譯C#加速器），--video產生MP4；每一種操作保留參數與種子。

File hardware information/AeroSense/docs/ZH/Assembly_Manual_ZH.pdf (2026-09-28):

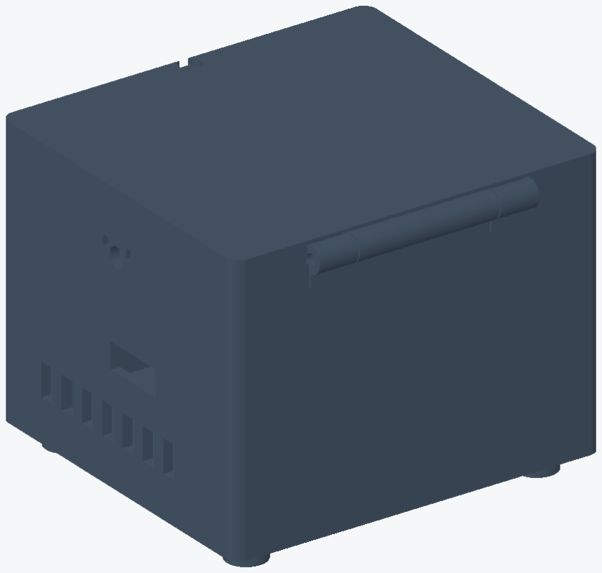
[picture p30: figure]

AeroSense | Engineering prototype | 2026-09-26 | 1

# AeroSense 組裝手冊

用途：四個液體獨立、气路共用的平底井，靠近原PCB四顆LED，一顆PD收光。PCB名目100×90 mm；原板尚未 製造。本手冊是一份完整的工程原型組裝流程，並未把名目CAD配合當成實板驗證。

先做順序：閱讀材料表 → 量測廠商板件資料 → 列印配合試片與乾式零件 → 不通電試裝 → 電子檢查 → 無細胞光 學／氣路測試 → 材料與細胞驗證。任何步驟不合格，就停在該步，不用硬壓零件或靠normalize掩蓋問題。

STL/根目錄共8個工作件。OPTION_accessible_cap中兩件會替代04內蓋，使整機變9件；不是再把兩個蓋子疊上 去。所有零件以mm輸出、無支撐，STL本身不攜帶單位。

# 1. 材料、工具與列印

零件 | 樹脂／數量
01一體主殼 | Rigid PC/GF-like Black ×1
02底座與PCB柱 | Aqua 8K Gray ×1
03鉸鏈外蓋 | Rigid PC/GF-like Black ×1
04氣路遮光內蓋 | Rigid PC/GF-like Black ×1
05四個平底well | Aqua Clear Plus ×4，NE/NW/SW/SE各1

Aqua Clear Plus為配合與材料試驗用，不是已驗證的HEK293T培養材。黑樹脂內蓋亦接觸樣本氣體，須測氣味吸 附、殘留與背景。Gray底座若透外光，使用同一STL改印Black，不增加件數。

用Sonic Mighty Revo 16K與實際樹脂批號校正，不猜曝光秒數。先做0.15 mm單邊滑配、M3螺帽槽及0.5 mm 底厚試片。大平面傾斜列印；井腔朝可排液方向，支撐避開液面接觸底、密封面及定位面。依原廠清洗、乾燥、 固化流程，測固化後尺寸。未清除的液態樹脂不能封在內腔。

工具：游標卡尺、塞尺、M3/M4對應六角匙、鑷子、小剪刀、適當防護、萬用表、示波器／邏輯分析儀；軟矽膠 片0.8 mm。完整數量與單價在獨立BOM工作簿。樹脂不可直接攻牙、硬敲或反覆彎折卡扣。

# 2. 座標、對位與送製前檢查


本圖採光學面朝上的組裝視角，D5封裝中心為(0,0)。LED中心名目(±3.3,±5.7)，液體井中心(±3.3,±2.65)。 D1=SW、D2=SE、D3=NE、D4=NW是PDF讀圖的暫定對應；須確認BOTTOM圖是否鏡像，不能只看左右猜接 線。

Vishay圖面光學中心距5 mm封裝底邊2.1 mm，因此沿長軸偏0.4 mm；方向取決於元件旋轉。模擬暫用(0,-0.4) ，並掃描反向。四井仍依LED定位。實際die形狀沒有被完整提供，模擬3×2.5 mm僅是7.5 mm²等面積近似。

向廠商索取：含元件STEP、板厚、四孔座標與孔徑、底面电池座含電池高度、USB-C與SW1插拔包络、LED出光 窗與PD旋轉。名目孔位±45/±40 mm、板厚1.6 mm不是廠商認證尺寸。

# 3. 風扇、PCB與底座

1. 斷電並移除電池。清除支撐、毛邊、粉屑，確認八件沒有翹曲或封閉樹脂囊。將M3螺帽放入對應捕捉槽，應平 貼且不能突出裝配面。
2. 將40×40×10 mm風扇放在02底座，中心(0,-12)，四孔距32 mm。用4組M4×20螺絲／墊片／螺帽固定。氣流 經底座吸入，流過PCB下方，再從電子艙開口排出。風扇不連通well氣路。
3. 確認風扇與固定件不碰板底元件：風扇本體上方允許23 mm元件高度，固定件上方僅16 mm，兩者都已預留2 mm名目間隙。電池座若進入較低區域，必須先改座位／高度，不能剪掉必要的PCB固定柱。
4. PCB光學面向上，放在四柱上。4顆M3×10螺絲配0.5 mm墊片固定，不壓電路、不使PCB彎曲。用塞尺確認板 底避空。5. 接風扇5V與GND需廠商確認接點及供電餘量，不能把LED gate當供電。做好絕緣與拉力固定，再用 另外4顆M3×10把主殼與底座固定。
6. 實板尚未到手，USB-C／SW1開口只能作名目試裝。應讓插頭外殼完全進出，開關全行程不摩擦，線材不掃到 光學部件。請把實測尺寸填入validation/fit_measurements.csv。

# 4. 光學、井與密封

7. 將PD不透光軟圈定位於封裝上，名目外4×4、內3×3.4 mm，原厚0.8壓至0.6。不可碰bond／元件端子；偏心 感光區到圈邊的裕量很小，必須向廠商確認window輪廓與旋轉，再測位置公差下遮擋比例。此尺寸不是已確認的 光學密封規格。
8. 濾片最大5.2×4.2×1 mm，放入座內，Z41.1至42.1。只在乾區角落固定，不把膠伸入光孔。透明色片不等於合 格發射濾片；需確認藍光完整波段阻擋與實際入射角下綠光透過率。
9. NE/NW/SW/SE各放入對應滑槽，讓凸緣落在Z56.8支承面。這是剛性卡匣滑入定位，不是彈性卡扣。四井外 底Z42.5、內底Z43，均為平面，底厚0.5 mm；井腔4.7×3.4 mm。名目150 µL時液面Z52.387，理論滿杯約 244.5 µL。先用無細胞液體量測實際容量。
10. 四孔井密封片外14×11.4 mm，孔中心(±3.3,±2.65)，每孔4.7×3.4 mm。0.8 mm片壓至0.6，由內蓋硬止擋 限制壓缩。不要遮住井口，也不要讓密封片擠入液體。四井氣體共用，不宣稱氣相隔離。

# 5. 內蓋、氣路與可開闔外蓋

11. 一體04內蓋包含完整水平孔板：12孔、直徑1.6 mm、厚1.2 mm，板Z63至64.2。孔板上方由負X側進氣，管 軸Z65.7；下方由正X側排氣，管軸Z61.5。兩端內徑2.4 mm，接尾外徑3.4、凸環4.0 mm。以2顆M3×10手轉螺 絲鎖到硬止擋，不靠大扭力壓井。

一體內蓋上層難以目視清洗和固化，只作乾式／無細胞試驗。需要可接近的清洗面時，改用OPTION兩件內蓋： 下件內建孔板，上件是屋頂，非對稱定位柱避免反放；增裁22×19、內孔15×12 mm密封圈。改2顆M3×12手轉 螺絲；總工作列印件9。仍需材質與密封試驗。

12. 進、排氣各接一個疏水0.2 µm氣體濾器。外部供氣須可控流量與限壓。不要堵住排氣、把氣體直接打入液體 ，或用風扇抽取培養井。關內蓋前先停止供氣，保持排氣經濾器通大氣，緩慢落蓋並對角輕鎖；確認壓力回到零 再供氣。
13. M3×75直桿穿過外蓋鉸鏈，加兩端墊片與尼龍防鬆螺帽，只限制滑出，不夾死轉軸。前端用1顆M3×12手轉 螺絲閉合。外蓋故意不做氣密活塞；真正的氣路密封在well與內蓋。

# 6. 更換、初驗與故障排除

更換井：停止量測 → LEDs關閉 → 停供氣且確認無壓 → 打開外蓋 → 鬆兩顆內蓋螺絲 → 垂直提蓋並托住軟管 → 用凸緣提起各井 → 依實驗室流程處理液體 → 換井及清潔密封面 → 重新暗訊號、基線和標準品校正。不能在含液 狀態翻轉整機。

現象 | 處理
well卡住／PCB受力 | 量收縮、毛邊、凸緣及板上元件高度；不硬壓。
ADC貼近0或滿刻度 | 查TIA、接線、外光和濾片；不可先normalize。
氣流低／壓力升高 | 停氣；查濾器濕潤、管折、堵孔、反接。
開關蓋後訊號跳動 | 查壓力脈衝、密封位移、外光及井定位重複性。
紫色透明井背景高 | 測光譜與空井自發螢光；拋光不能去除材料體吸收。

乾式驗收：無碰件、無彎板、螺帽全咬合、井可手動取放、開蓋不拉管、連接器可插拔。含液驗收：固定容量下 靜置、傾斜與開蓋循環皆無液體接觸PCB，使用溫度下壓力與流量可重複。未完成這些記錄前，不把CAD渲染當 成實物照片或成功證據。

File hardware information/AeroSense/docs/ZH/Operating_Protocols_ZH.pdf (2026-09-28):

AeroSense | Engineering prototype | 2026-09-26 | 1

# 操作與驗證流程

本文件提供可執行的工程測試順序、資料欄位與暫定放行門檻。門檻是本專案的起始工程要求，不是公認 GCaMP6f／HEK293T生物安全標準。先在測試計畫中登錄，失敗也保留原始資料。

階段 | 輸入／產物
A 電子 | 電源、D1-D4頻率／電流、ADC波形、原始碼值
B 空白光學 | 暗、空井、培養液、無GCaMP細胞、螢光標準
C 氣路與機構 | 流量／壓差、漏液、關蓋壓力脈衝、20次更換
D 細胞與標準品 | 細胞批次、密度、受體、參考刺激、存活與pH
E 分析 | 原始I/Q、校正矩陣、正規化、獨立批次驗證

每次記錄：操作者匿名代碼、日期、device ID、firmware與CAD檔案雜湊、樹脂批次及固化紀錄、井別與細胞批 次、填充量、溫度、濕度、CO2／pH、標準氣體濃度與單位、流量、曝光duty、濾器／濾片型號。缺少單位的濃 度資料不進模型訓練。

# A. PCB上電與四頻取樣

1. 由廠商先確認電源路徑、電池極性、SW1、3.3V數位／類比及2.5V參考。以限流電源開始，記錄空載、Wi-Fi、 每顆LED和風扇的電壓／電流／溫升。風扇候選最大另需157 mA@5V（0.785 W）；不能假設原設計有此餘量。
2. 示波器看GPIO25/26/27/32及MOSFET drain；對應D1-D4。固定41/67/89/113 Hz，先低duty短時測試，量 實際LED電流與光功率。Duty改變的是脈衝比例，不是恆流振幅。確認關機、停止、錯誤與重啟時全部關燈。
3. ADS8866：GPIO33 CONVST、18 SCLK、19 DOUT，DIN由硬體拉高。核對CONVST高至少8.8 µs後才讀； 實作等待10 µs，SPI mode0、2 MHz、16位MSB first。以已知輸入確認零點、中量程與增益，VREF實測代入。 不可直接把高電壓訊號接上ADC。
4. 每組2秒、4 kS/s共8000點。暫定：不漏點、無rail samples、取樣間隔最大誤差50 µs；不合格組標invalid。 這個門檻不是準確度證明，須再量測同步串擾及振幅誤差。示波器確認程式時序後，才允許 BOARD_VALIDATED=true。
5. 用稳定可控光源做至少5個強度、每級10組，量線性、暗噪聲、重复性与LED切換串擾。提議起始目標：中量程 重複CV5%、擬合殘差5%；全量程不飽和。實際檢出限需由空白分布與低濃度重複實驗推定。

# B. 光學校正與紫色樹脂

同一批固化試片做0.5／1／2 mm厚度，測完整LED發射範圍與GCaMP發射範圍的穿透光譜，另量散射與空白螢 光。使用空白參考與相同曝光，至少3件試片，報平均、標準差、厚度及儀器校正。Beer-Lambert可估體吸收， 但表面反射和散射需分辨。

紫色可能來自吸收或染料／光引發劑，拋光只改善表面散射。若高背景或波段衰減隨批次、固化、浸泡時間改變 ，不能用單一倍率修正。快速路徑：先用透明井做無細胞光學空白；不合格則停止採用該樹脂作正式光窗，改用 已驗證材料的光窗／培養容器，機構需重新配合。

光學串擾矩陣：固定LED與電子設定，每次只在一個井放同一穩定螢光標準，其他三井放匹配空白；記錄四頻複 數I/Q，四個井各重複至少5次。所得M的列為LED頻率、欄為well，使用y=Mx+b。先扣除複數背景b，再求x； 量測條件一致且矩陣條件數<30才嘗試反解。30是暫定工程門檻，需報誤差傳播。

GCaMP陰性細胞／培養液的同步訊號可來自漏藍光或樹脂，DLIA不會消除與LED同頻的背景。濾片須經實測入射 角與光譜證明；採購OD規格不是本機漏光比例。

# C. 氣路、壓力與組裝穩定

在無細胞液體下測無孔板對照與選定孔板，建議掃0.25／0.5／1 mL/min。這是初始量測範圍，不是已證實細胞 可耐受流量。兩端濾器、接管與內蓋需同時在位。記錄入口／出口流量、兩端壓差、關蓋瞬時壓力、質量變化及 液面擾動。

孔板的孔速約Q/A_open；在定流量下減少開孔面積會增加孔速。模擬不含濾器，實際濾器可能主導壓降。閉蓋 時若所有氣路堵死，ΔP約P_atm×ΔV/V：即使只壓縮1%氣體也約1 kPa，遠大於此模型約0.01 Pa的內艙流阻。保 持過濾排氣暢通、低速閉蓋比「把所有地方封死」重要。

密封目標需依暴露規格制定：先量儀器本身流量誤差，再評估入口與出口差值；差值不能只用單一數值判斷漏氣 ，也可能是量測誤差或暫態。排氣濾器一旦濕潤、堵塞或壓力异常，立即停止。不能用這個殼當壓力容器。

組裝穩定試驗：同一空白或螢光標準，20次取放井／開關蓋，每次相同液量与設定，記錄四通道、漏液、定位、 零件損壞与所需時間。先以訊號CV5%作起始目標，並與未拆裝的時間漂移對照分開。孔板不一定改善均匀度； 必須報失敗結果。

# D. 細胞與參考刺激

使用HEK293T，並非細菌。培養、來源驗證、黴漿菌、廢棄及操作應遵循所在地實驗室對該細胞株的核准流程。 外殼濾器與密封片不等於生物安全櫃，樹脂光學合格也不等於細胞相容。

先做材料浸出液與直接接觸對照：商用培養容器作基準，匹配细胞批次、密度、培養液、受體／GCaMP表達與觀 察時間；至少3個獨立細胞批次。記錄形態、貼附、存活、pH、基線及參考刺激反應，不能只比較總亮度。

目前機構没有加熱、細胞溫度或CO2感測器。短時離開培養環境也可能改變pH與反應。記錄實際液體溫度、緩衝 系統、CO2、濕度與蒸發；若需要持續培養，需外部環控或新增設計，風扇不能取代培養控制。

參考品優先選已確認能啟動該受體、穩定可取得、濃度可追溯的氣味標準；空白用同一載氣。濃度先由劑量反應 實驗選在可重複且未飽和的範圍。鈣離子相關藥劑可檢查下游反應，但不等於受體對氣味的陽性對照；不可假定 每次使用不影響後續細胞。此處不捏造尚未指定受體的通用濃度或藥劑配方。

建議每批：空白 → 基線 → 標準品 → 回復確認 → 隨機化樣本與空白 → 結尾標準品。若標準品造成不可逆漂移， 改用獨立參考井／平行批次，而不是強制重複刺激同一井。四井共享氣體，不能把其中一井稱為「未暴露氣體對 照」。

# E. Normalize、效能與模型驗證

儀器層先校正gain、phase和背景，生物層才算ΔF/F0=(F-F0)/F0。介面先逐頻率扣除複數暗訊號，再取振幅。基 線F0與標準刺激各至少5個有效組；F0接近噪聲時拒絕除法。標準品正規化R=(F-F0)/(Fref-F0)，分母不足5倍暗 訊號噪聲時不輸出R。

每個頻率的LED直接激發量可能不同，四井不能互相當成相同尺度。若沒有實測M，介面顯示的是LED通道正規化 ，不是假裝已解出獨立細胞井。校正不能補救飽和、非線性、材料光譜变化或受體失活。

效能測試至少包含：空白分布、反應時間與回復、量程／劑量反應、日內及跨日重複性、交叉氣味、濕度／溫度 干擾、記憶效應與清洗、光漂白与光毒、裝配循環。以實驗批次為生物n；同一批的多個時間窗是技術重複。報原 始資料、排除理由、平均與區間，不只挑漂亮曲線。

NN以cell batch／day／device分組切訓練與測試，不能把同一run的相鄰時間窗拆到兩邊。特徵正規化只用訓練 集。交付的小型MLP可訓練和推論，但沒有實驗標籤資料，因此不附虛構氣味辨識模型或準確率。需留前瞻測試 集，報混淆矩陣、各類召回、無反應／未知類及失敗模式。

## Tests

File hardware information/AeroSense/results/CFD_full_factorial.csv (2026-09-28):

case | d_mm | holes | gap_mm | converged | dp_Pa | mean_head_mm_s | worst_head_mm_s | mean_head_fixed_dp_mm_s | Q_at_0p01Pa | mass_imbalance
holes_4 | 1.6 | 4 | 1.5 | True | 0.014894044528644833 | 0.0017513627914496975 | 0.002149726517139969 | 0.00117588126454262 | 0.67140929925163 | 0.0008892748882670298
d1p6_n4_h3 | 1.6 | 4 | 3.0 | True | 0.014520667136845213 | 0.0036622991879238192 | 0.004159037478020148 | 0.0025221287378945434 | 0.6886735923190247 | 0.000980012873756282
d1p6_n4_h4p5 | 1.6 | 4 | 4.5 | True | 0.01412933455060419 | 0.0034318700907661178 | 0.003920852797295741 | 0.0024288971844179078 | 0.7077474147267881 | 0.0011264123828370611
holes_6 | 1.6 | 6 | 1.5 | True | 0.014417587310147412 | 0.0015168111581920322 | 0.0019516804546980842 | 0.00105205616277036 | 0.6935973256053585 | 0.0008804968547000976
d1p6_n6_h3 | 1.6 | 6 | 3.0 | True | 0.014043296370724117 | 0.003451084035260354 | 0.003649041284779614 | 0.002457460089252824 | 0.7120835262614607 | 0.001007027062615411
d1p6_n6_h4p5 | 1.6 | 6 | 4.5 | True | 0.013651471044261348 | 0.003218655486973857 | 0.003430905952188992 | 0.0023577352774204353 | 0.7325217895989082 | 0.0011336087266032456
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

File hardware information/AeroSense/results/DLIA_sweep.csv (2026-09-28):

duration_s | noise_V | timestamp_jitter_us | max_relative_amplitude_error | residual_rms_V
0.5 | 0.0001 | 0 | 0.0005874969199268776 | 9.944380559628173e-05
0.5 | 0.0001 | 1 | 0.0007540497183395889 | 9.855035354215048e-05
0.5 | 0.0001 | 10 | 0.00010538305512008961 | 9.963762670642219e-05
0.5 | 0.0001 | 50 | 0.0002481103740277213 | 0.0001019143422377283
0.5 | 0.001 | 0 | 0.001700638938804122 | 0.0009817778168932883
0.5 | 0.001 | 1 | 0.004290439995108697 | 0.0010028049507107791
0.5 | 0.001 | 10 | 0.0022420835830677666 | 0.0009832968242665953
0.5 | 0.001 | 50 | 0.0018774663201789332 | 0.0010080263207896815
0.5 | 0.01 | 0 | 0.008160274373006926 | 0.010306038715817542
0.5 | 0.01 | 1 | 0.008462832743801219 | 0.009773288270925098
0.5 | 0.01 | 10 | 0.03353941041910047 | 0.009660128802189513
0.5 | 0.01 | 50 | 0.012632641386373433 | 0.009899659577902953
1 | 0.0001 | 0 | 0.0001559301906435273 | 9.907007059663756e-05
1 | 0.0001 | 1 | 0.00014360725522366558 | 9.863555588708878e-05
1 | 0.0001 | 10 | 0.00015628373970111298 | 9.929374249175357e-05
1 | 0.0001 | 50 | 0.0005212948524492278 | 9.962963716005374e-05
1 | 0.001 | 0 | 0.000978224207128342 | 0.001018673009882755
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

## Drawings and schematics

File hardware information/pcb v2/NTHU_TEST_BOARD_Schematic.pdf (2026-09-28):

# U2 BQ24074

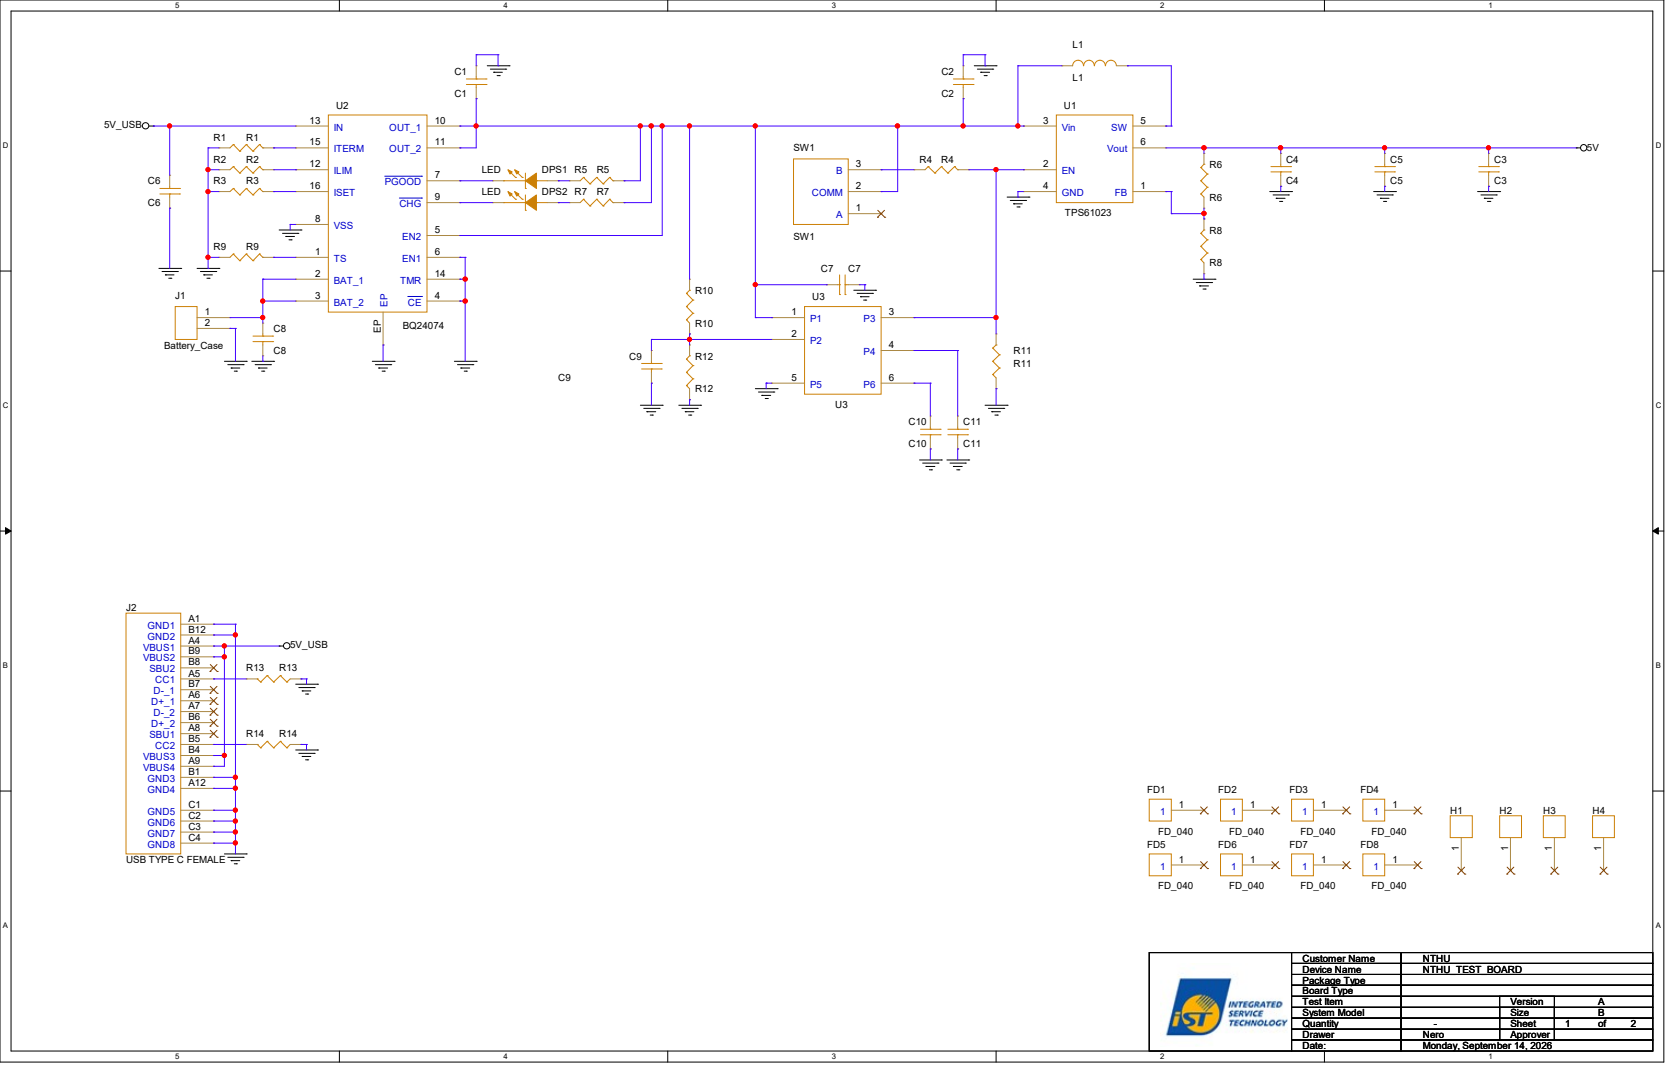
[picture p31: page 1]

Board Type Test Item

# 3V3 LDO

EN

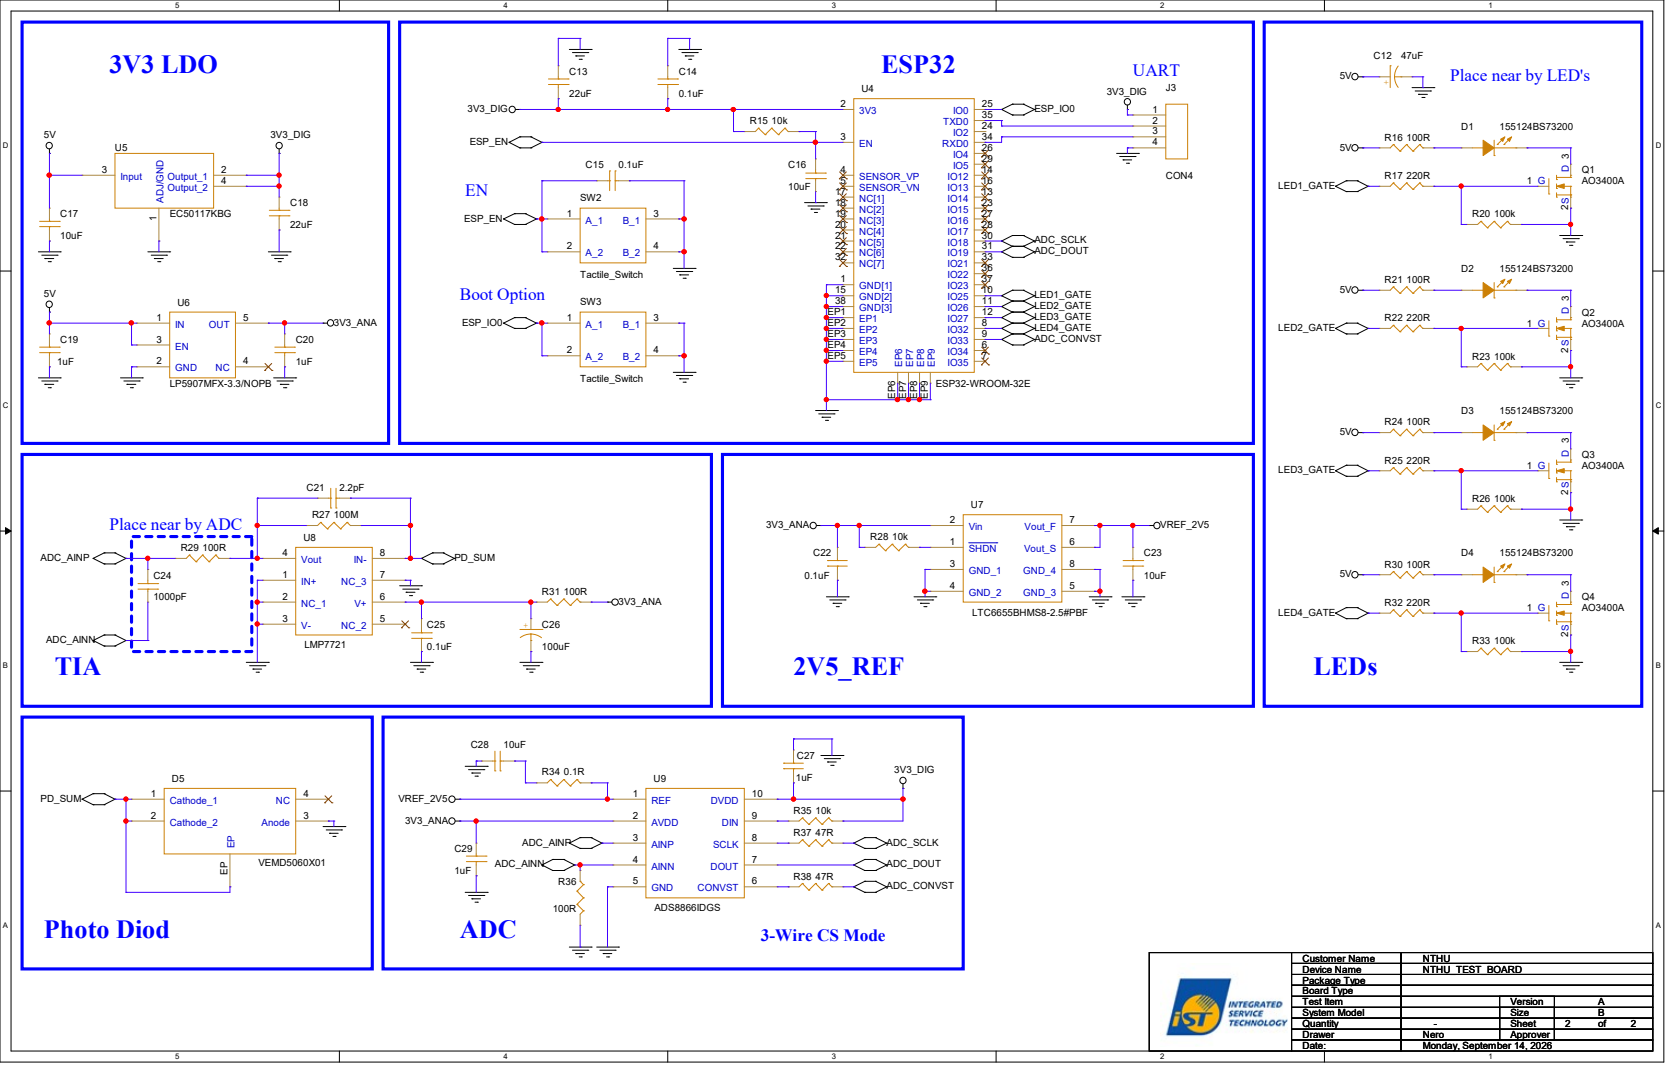
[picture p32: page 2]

Place near by LED's

Place near by ADC

Board Type Test Item

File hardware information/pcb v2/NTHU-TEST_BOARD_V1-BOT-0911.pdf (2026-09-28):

## ART FILM - PDF_BOTTOM

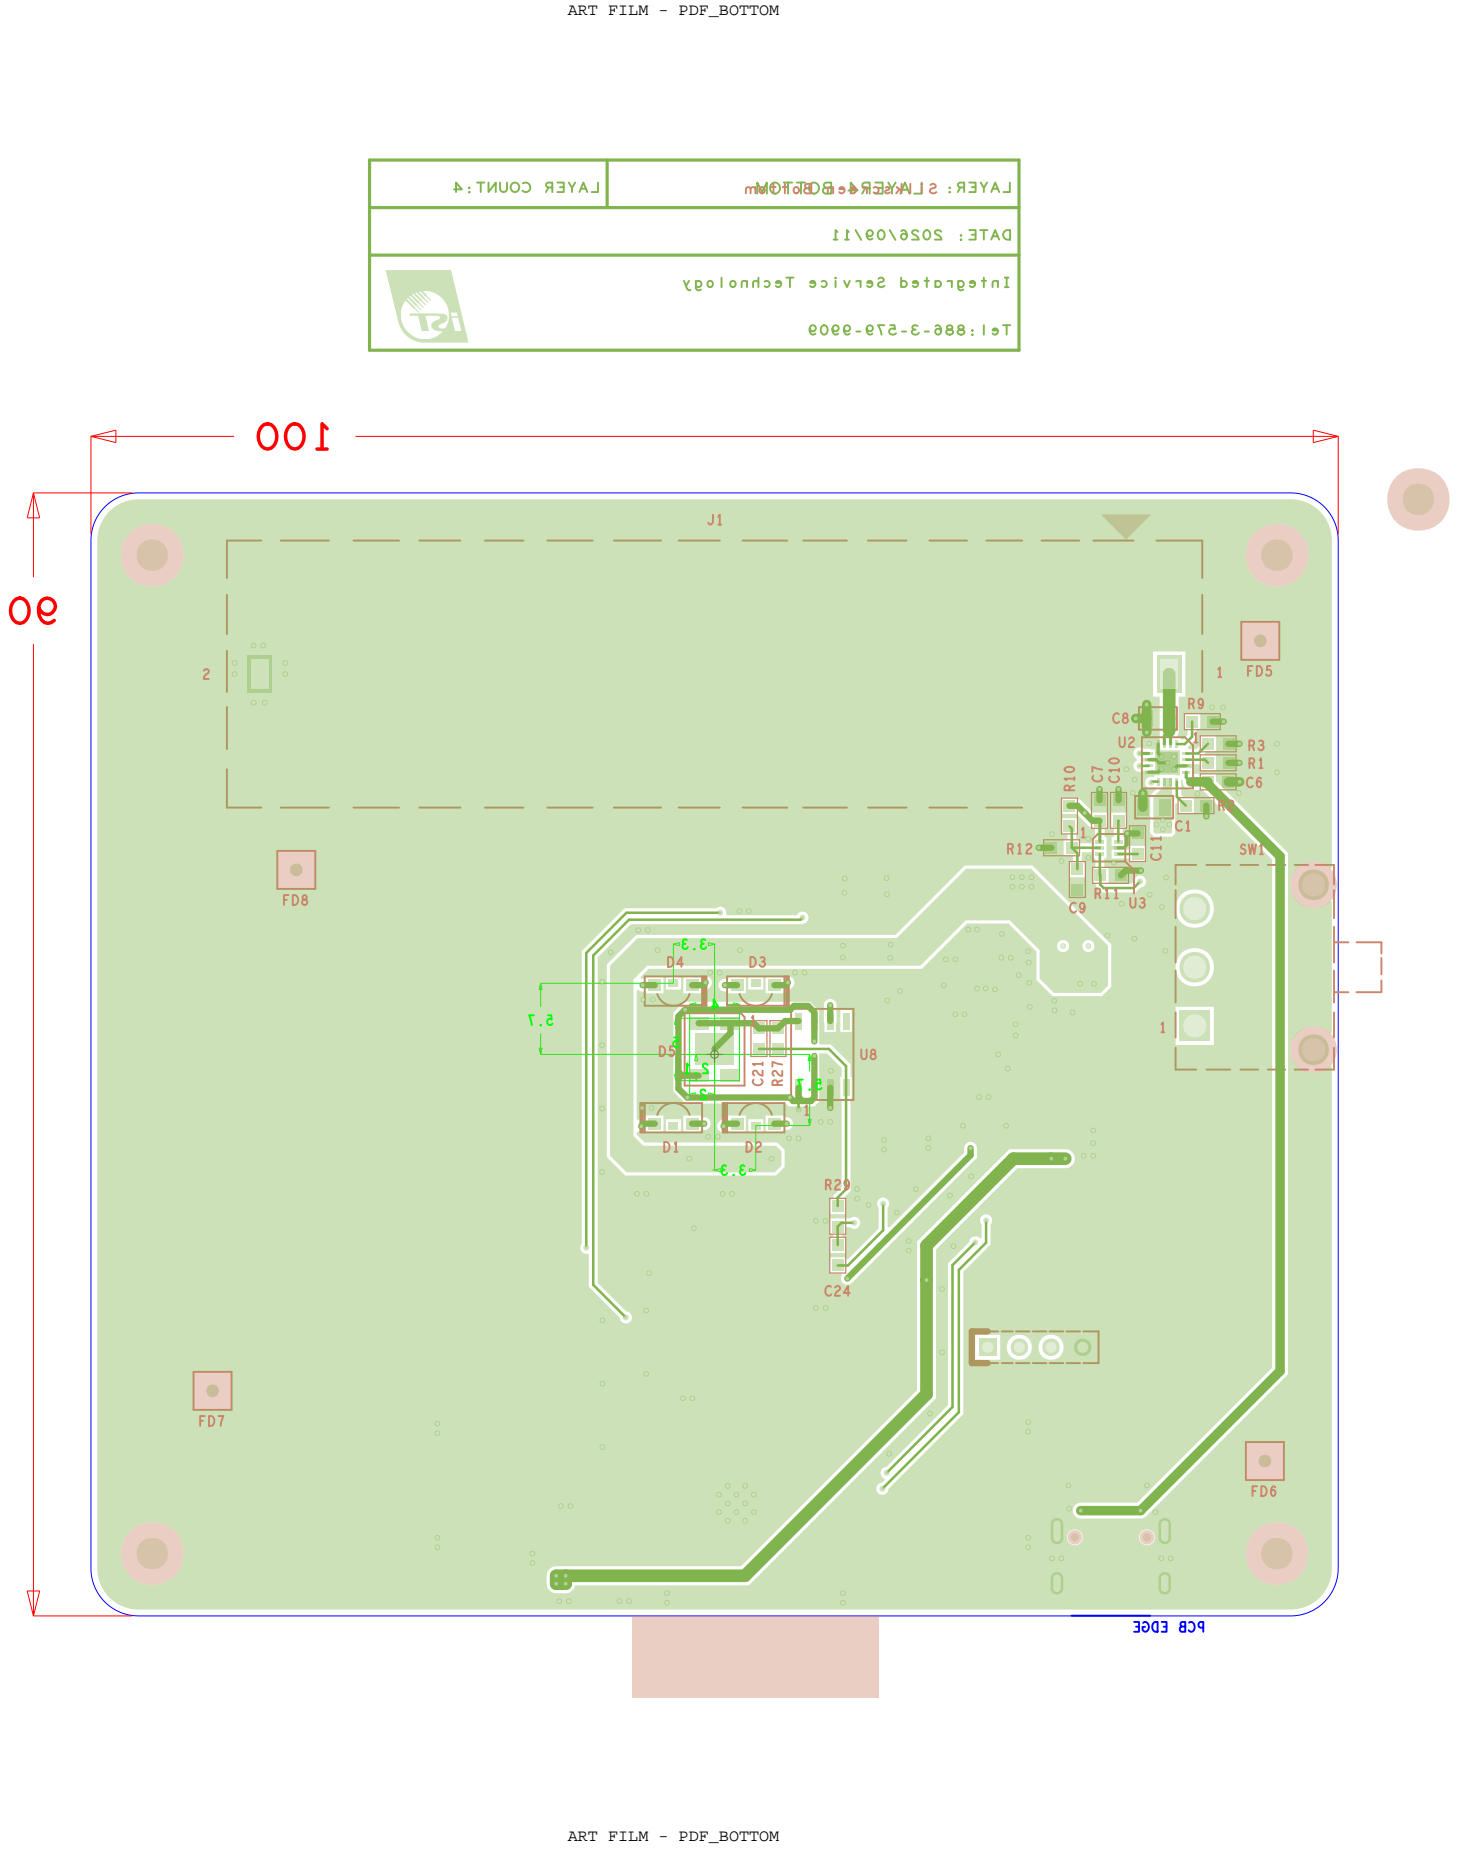
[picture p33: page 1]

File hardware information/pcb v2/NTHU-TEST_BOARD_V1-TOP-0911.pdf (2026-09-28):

## ART FILM - PDF_TOP

100

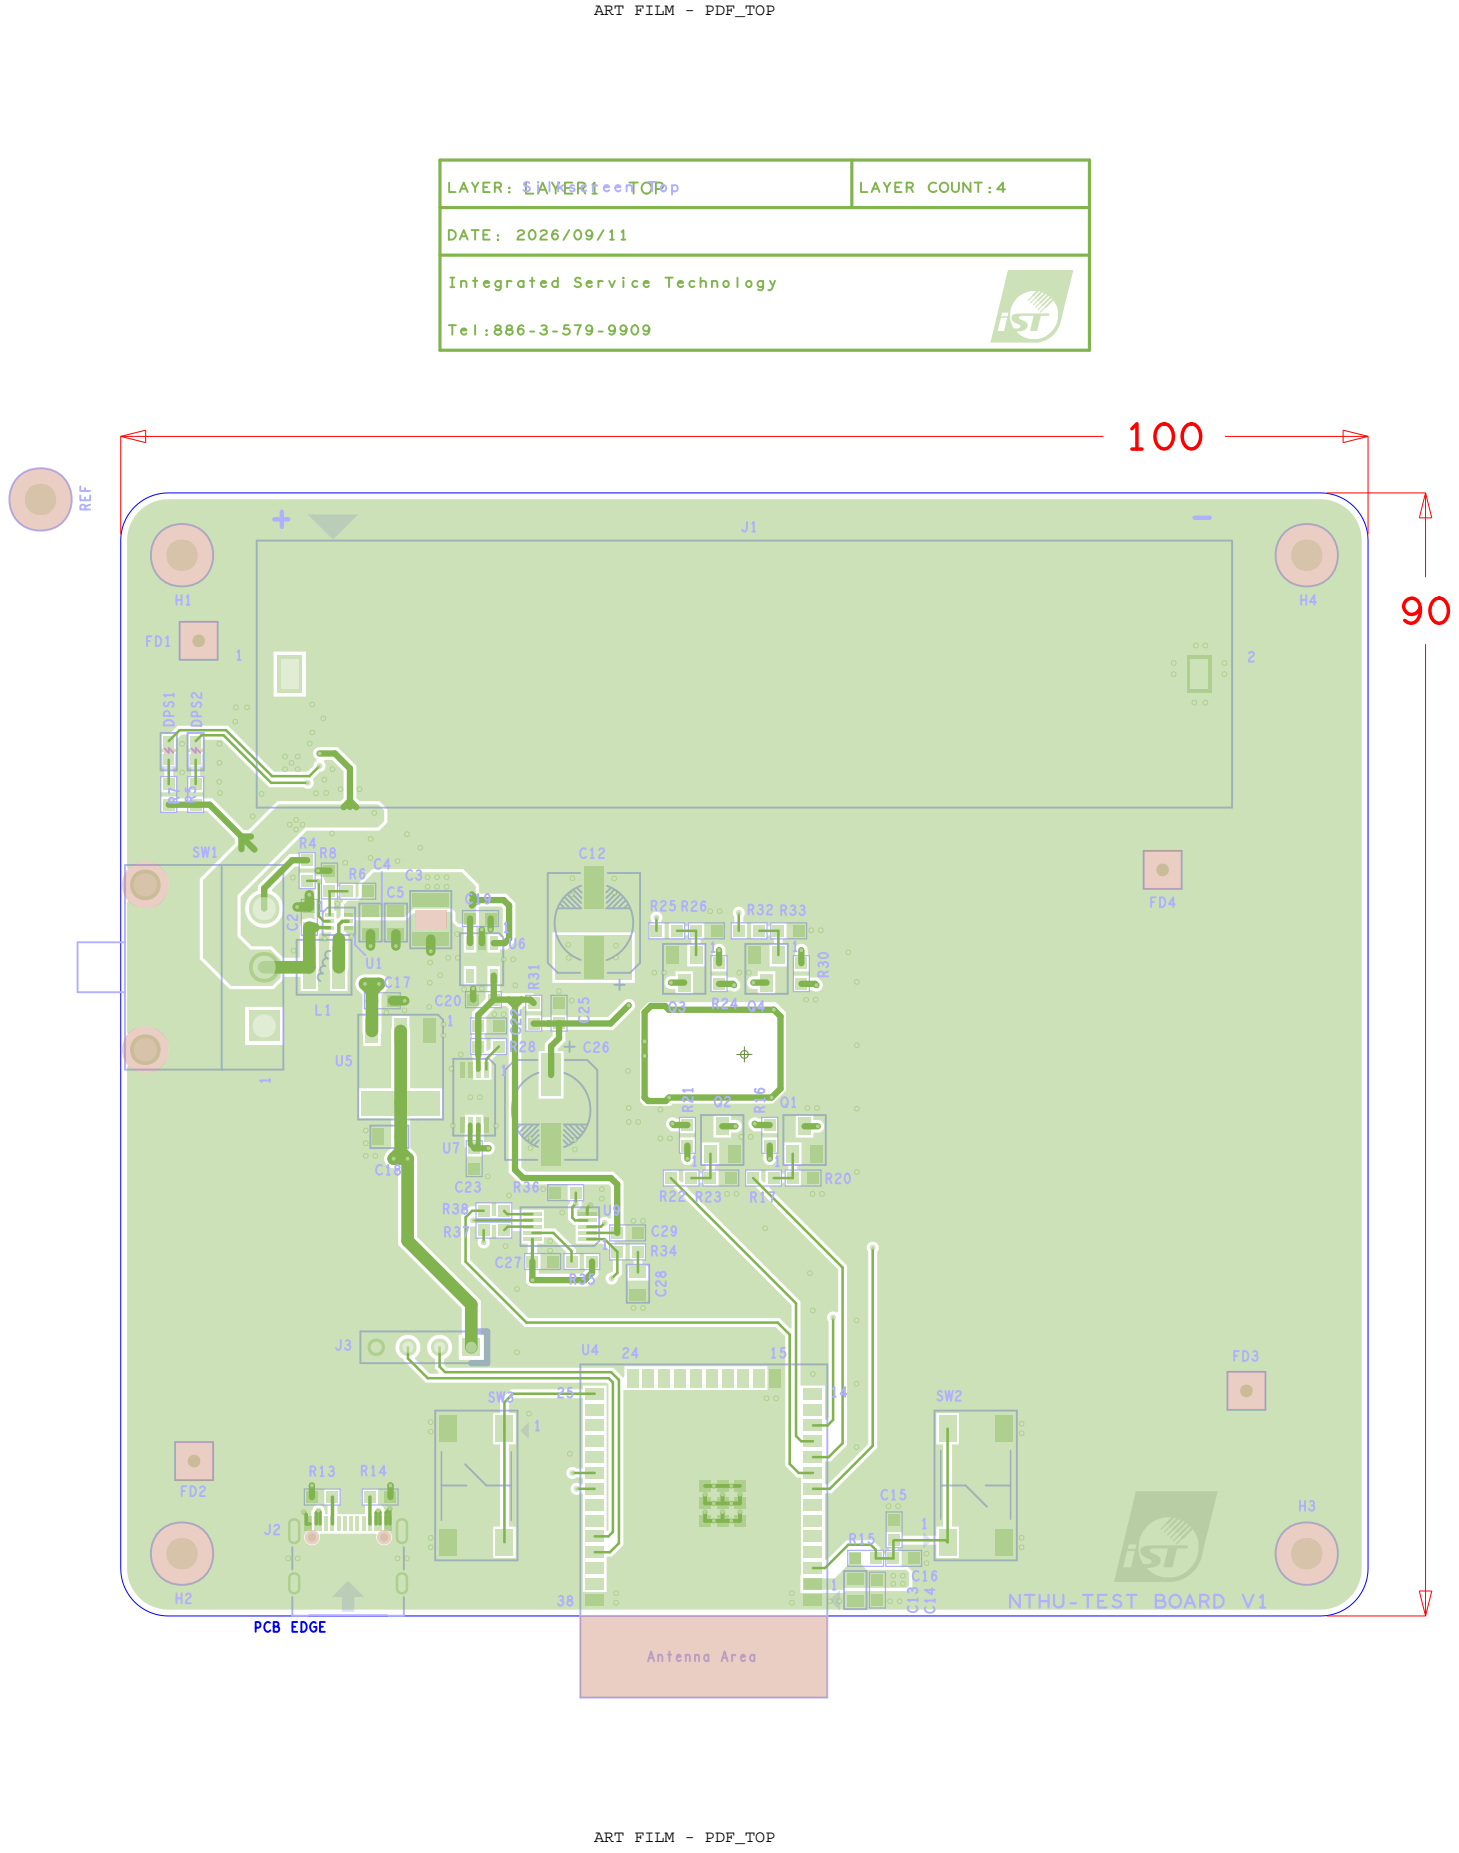
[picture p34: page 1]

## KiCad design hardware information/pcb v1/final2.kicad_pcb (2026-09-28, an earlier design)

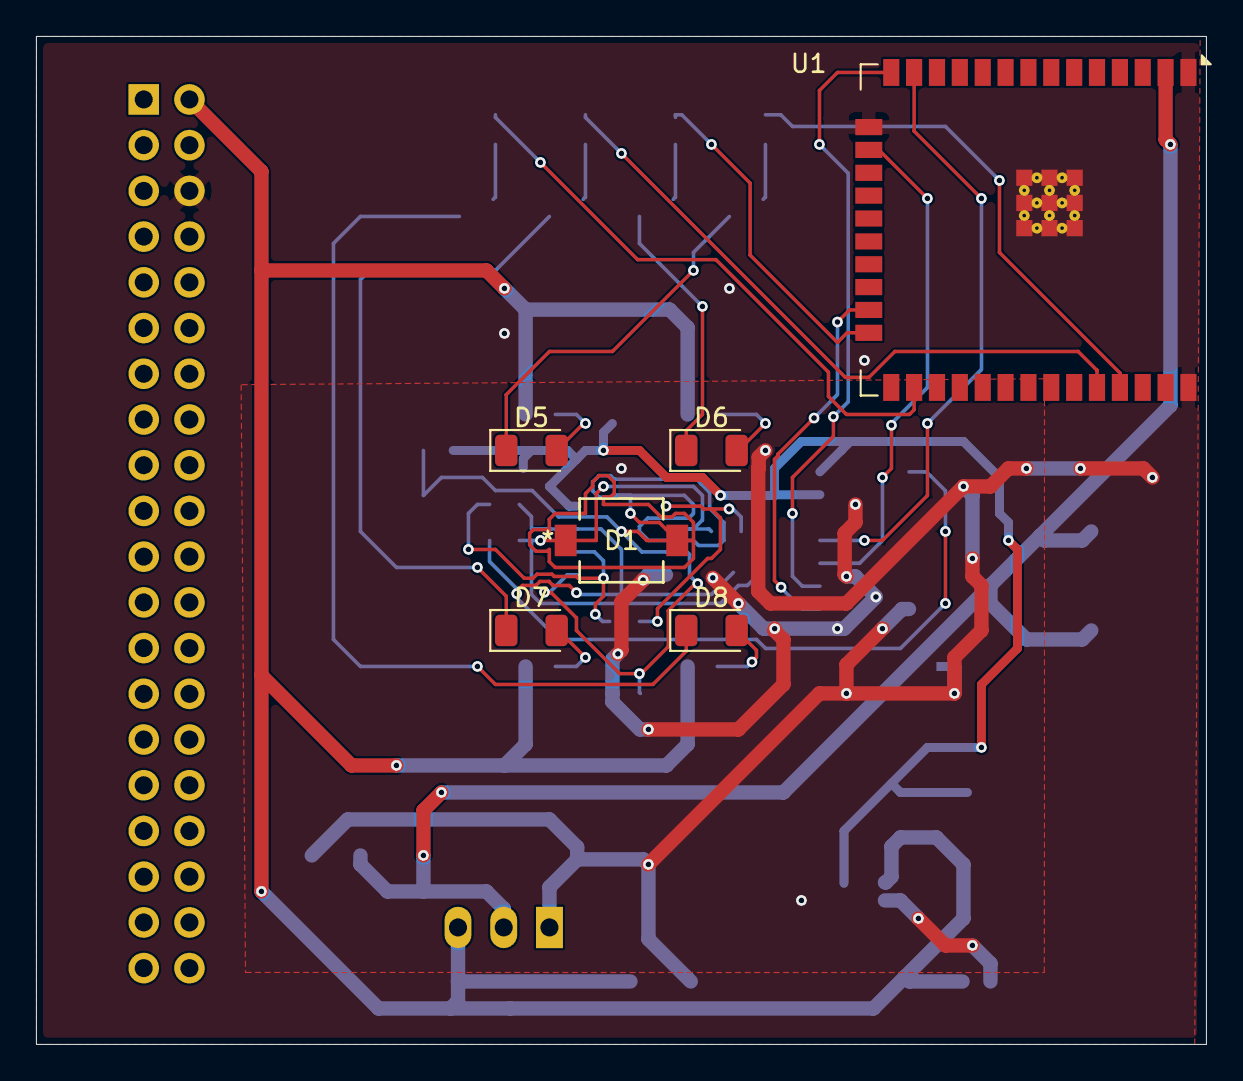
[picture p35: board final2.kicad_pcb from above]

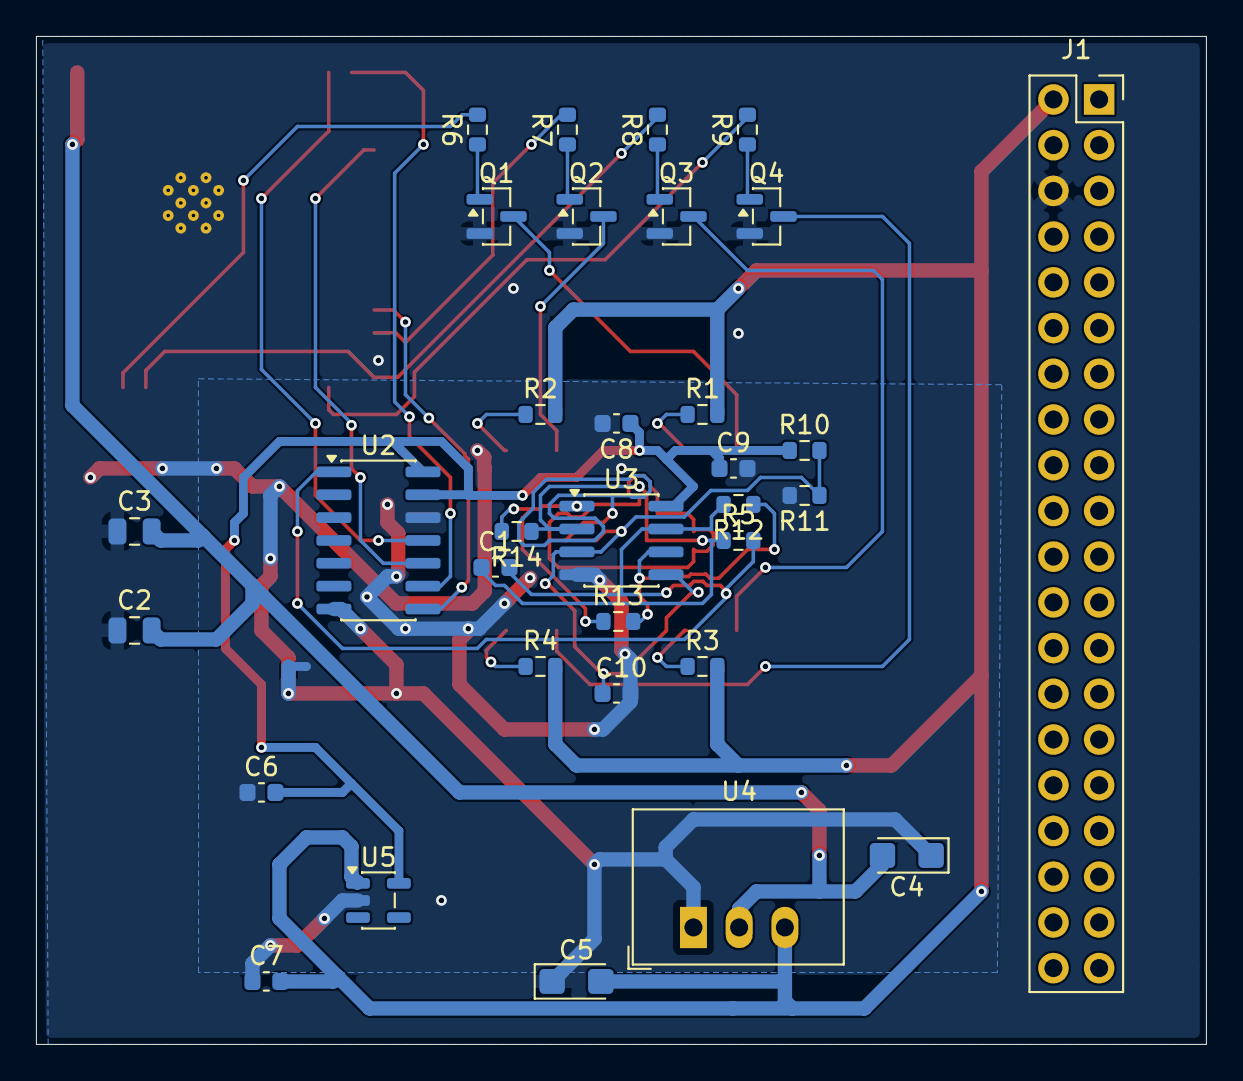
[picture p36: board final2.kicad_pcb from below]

Board: 2 copper layers, 65.0 x 56.0 mm, 40 parts (34 on the bottom side), 30 nets.

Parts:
C1, C6, C7, C8, C9, C10: C_Small; C_0603_1608Metric
C2, C3: C_Small; C_0805_2012Metric
C4, C5: C_Small; CP_EIA-3216-18_Kemet-A
D1: D_Photo; LED_VBPW34S_VIS
D5, D6, D7, D8: LED; LED_1206_3216Metric
J1: Conn_02x20_Odd_Even; PinSocket_2x20_P2.54mm_Vertical
NT1: NetTie_2; NetTie-2_SMD_Pad0.5mm
Q1, Q2, Q3, Q4: AO3400A; SOT-23
R1, R2, R3, R4: R_Small_47R; R_0603_1608Metric
R5: R_Small_10MR; R_0603_1608Metric
R6, R7, R8, R9, R10, R11, R12, R13, R14: R_Small; R_0603_1608Metric
U1: ESP32-WROOM-32E
U2: MCP3204; SOIC-14_3.9x8.7mm_P1.27mm
U3: LM358; SOIC-8_3.9x4.9mm_P1.27mm
U4: AMS1117CD-3.3; Converter_DCDC_RECOM_R-78E-0.5_THT
U5: LP5907MFX-3.3; SOT-23-5

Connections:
/1R: R13.1, R14.2, U3.1
/3.3V_ANA: C6.2, C8.1, C9.1, R10.1, U2.13 (Vref), U2.14 (Vdd), U3.8 (V+), U5.5 (OUT)
/3.3V_DIG: C2.2, C3.2, C4.2, U1.2 (VDD), U4.2 (VO)
/ADC_CH1_IN: C1.2, R5.2, R12.2, U2.1 (CH0), U3.7
/GND: C2.1, C3.1, C4.1, C5.1, J1.6, NT1.1, Q1.2 (S), Q2.2 (S), Q3.2 (S), Q4.2 (S), U1.1 (GND), U1.15 (GND), U1.38 (GND), U1.39 (GND), U2.7 (DGND), U4.1 (GND)
/GNDA: C6.1, C7.1, C8.2, C9.2, C10.2, NT1.2, R11.2, U2.12 (AGND), U3.4 (V-), U5.2 (GND)
/LEDA1: D5.1 (K), Q1.3 (D)
/LEDA2: D6.1 (K), Q2.3 (D)
/LEDA3: D7.1 (K), Q3.3 (D)
/LEDA4: D8.1 (K), Q4.3 (D)
/LEDC1: D5.2 (A), R1.1
/LEDC2: D6.2 (A), R2.1
/LEDC3: D7.2 (A), R3.1
/LEDC4: D8.2 (A), R4.1
/PD2TIA: C1.1, D1.1 (K), R5.1, R14.1, U3.2 (-)
/PWM_CH1I: R6.2, U1.35 (TXD0/IO1)
/PWM_CH1O: Q1.1 (G), R6.1
/PWM_CH2I: R7.2, U1.24 (IO2)
/PWM_CH2O: Q2.1 (G), R7.1
/PWM_CH3I: R8.2, U1.34 (RXD0/IO3)
/PWM_CH3O: Q3.1 (G), R8.1
/PWM_CH4I: R9.2, U1.26 (IO4)
/PWM_CH4O: Q4.1 (G), R9.1
/R6: R12.1, R13.2, U3.6 (-)
/SPI_CLK: U1.13 (IO14), U2.11 (CLK)
/SPI_CS: U1.23 (IO15), U2.8 (~CS/SHDN)
/SPI_MISO: U1.16 (IO13), U2.10 (Dout)
/SPI_MOSI: U1.14 (IO12), U2.9 (Din)
/USB_5V: C5.2, C7.2, J1.2, R1.2, R2.2, R3.2, R4.2, U4.3 (VI), U5.1 (IN)
/V_MID: C10.1, D1.2 (A), R10.2, R11.1, U3.3 (+), U3.5 (+)

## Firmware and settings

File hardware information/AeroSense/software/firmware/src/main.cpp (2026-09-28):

// ESP32-WROOM-32E / vendor NTHU schematic sheet 2. No invented sensors.
// Finite 2 s acquisition blocks; hardware timer DDS and timestamped ADC samples.
#include <Arduino.h>
#include <WiFi.h>
#include <WebServer.h>
#include <HTTPClient.h>
#include <WiFiClientSecure.h>
#include <SPI.h>
#include <LittleFS.h>
#include <ArduinoJson.h>
#include <soc/gpio_struct.h>
#include <esp_timer.h>
#if __has_include("aerosense_config.h")
#include "aerosense_config.h"
#else
#include "config.example.h"
#endif
constexpr int FS=4000,N=8000,CNV=33,MISO_PIN=19,SCLK_PIN=18;
const int LED[4]={25,26,27,32};
volatile uint32_t tick=0,stamp=0;volatile bool acquiring=false,completed=false,abortFlag=false;
uint16_t raw[N];uint32_t ts[N];
int freq[4]={41,67,89,113},phase[4]={0,0,0,0},duty=25,mask=15;
TaskHandle_t sampler=nullptr;hw_timer_t* timer=nullptr;WebServer http(80);
String state="idle",fault="",latest="null",lastCommand="";
int count=0,intervalSec=3,remaining=0;uint32_t nextStart=0,sequence=0;
String bootId,outbox[8],lastAck="";int outCount=0;
void IRAM_ATTR lightsOff(){GPIO.out_w1tc=(1UL<<25)|(1UL<<26)|(1UL<<27);GPIO.out1_w1tc.val=1;}
void IRAM_ATTR timerISR(){
 if(!acquiring)return;
 if(tick>=N){acquiring=false;lightsOff();return;}
 stamp=micros();
 for(int j=0;j<4;j++){
  phase[j]=(phase[j]+freq[j])%FS;
  bool on=(mask&(1<<j)) && phase[j]<FS*duty/100;
  if(LED[j]<32){if(on)GPIO.out_w1ts=1UL<<LED[j];else GPIO.out_w1tc=1UL<<LED[j];}
  else {if(on)GPIO.out1_w1ts.val=1;else GPIO.out1_w1tc.val=1;}
 }
 tick++;BaseType_t wake=pdFALSE;vTaskNotifyGiveFromISR(sampler,&wake);if(wake)portYIELD_FROM_ISR();
}
void sampleTask(void*){
 for(;;){uint32_t notifications=ulTaskNotifyTake(pdTRUE,portMAX_DELAY);
  if(!acquiring)continue;
  uint32_t k=tick;
  if(notifications!=1 || k!=(uint32_t)count+1 || abortFlag){abortFlag=true;acquiring=false;lightsOff();completed=true;continue;}
  uint32_t now=micros();ts[count]=now;
  digitalWrite(CNV,HIGH);delayMicroseconds(10); // ADS8866 tconv,max=8.8 us
  digitalWrite(CNV,LOW); // MSB valid before first rising clock
  SPI.beginTransaction(SPISettings(2000000,MSBFIRST,SPI_MODE0));raw[count]=SPI.transfer16(0);SPI.endTransaction();
  if(micros()-now>200 || now-stamp>50)abortFlag=true;
  count++;
  if(count==N || abortFlag){acquiring=false;lightsOff();completed=true;}
 }
}
void beginBlock(){
 if(!BOARD_VALIDATED && mask!=0){fault="board_not_validated";state="fault";remaining=0;return;}
 timerAlarmDisable(timer);ulTaskNotifyValueClear(sampler,0xffffffff);count=0;tick=0;abortFlag=false;completed=false;
 for(int j=0;j<4;j++)phase[j]=0;
 timerWrite(timer,0);acquiring=true;state="measuring";timerAlarmEnable(timer);
}
void finishBlock(){
 timerAlarmDisable(timer);lightsOff();completed=false;
 DynamicJsonDocument d(4096);d["id"]=bootId+"-"+String(++sequence);d["mode"]="hardware";d["sampleRateHz"]=FS;d["samples"]=count;d["dutyPercent"]=duty;d["ledMask"]=mask;
 d["batteryPercent"]=nullptr;d["cellTemperatureC"]=nullptr;d["firmware"]="AeroSense";
 int lo=65535,hi=0,rails=0;double mean=0,var=0,maxErr=0,jitter2=0,I[4]={},Q[4]={};
 for(int i=0;i<count;i++){lo=min(lo,(int)raw[i]);hi=max(hi,(int)raw[i]);rails+=(raw[i]<32 || raw[i]>65503);mean+=raw[i]*2.5/65536.;}
 if(count)mean/=count;
 for(int i=0;i<count;i++){
  double v=raw[i]*2.5/65536.-mean;var+=v*v;
  if(i){double e=(int32_t)(ts[i]-ts[i-1])-250.;maxErr=max(maxErr,abs(e));jitter2+=e*e;}
  // Reference is tied to LED DDS tick. Timing jitter is exported and invalidates bad blocks.
  for(int j=0;j<4;j++){double a=2*PI*freq[j]*(i+1)/FS;I[j]+=v*cos(a);Q[j]+=v*sin(a);}
 }
 auto fs=d.createNestedArray("frequenciesHz");auto ia=d.createNestedArray("inPhaseV");auto qa=d.createNestedArray("quadratureV");auto aa=d.createNestedArray("amplitudeV");
 for(int j=0;j<4;j++){fs.add(freq[j]);double iv=count?2*I[j]/count:0,qv=count?2*Q[j]/count:0;ia.add(iv);qa.add(qv);aa.add(sqrt(iv*iv+qv*qv));}
 bool valid=!abortFlag && count==N && rails==0 && maxErr<=50;
 d["valid"]=valid;d["adcMin"]=lo;d["adcMax"]=hi;d["railSamples"]=rails;d["meanV"]=mean;d["rmsV"]=count?sqrt(var/count):0;
 d["maxIntervalErrorUs"]=maxErr;d["rmsIntervalErrorUs"]=count>1?sqrt(jitter2/(count-1)):0;d["note"]="LED-channel amplitudes; not independently unmixed wells";
 d["error"]=abortFlag?"sample_timing_or_overrun":rails?"ADC_rail":maxErr>50?"sample_jitter":"";
 latest="";serializeJson(d,latest);
 if(strlen(CLOUD_URL)){
  if(outCount<8)outbox[outCount++]=latest;
  else {valid=false;fault="upload_queue_full";}
 }
 if(!valid){if(fault.isEmpty())fault=d["error"].as<String>();state="fault";remaining=0;}else{remaining--;state=remaining>0?"waiting":"idle";nextStart=millis()+intervalSec*1000;}
}
bool auth(){if(http.header("X-Aero-Key")==API_KEY)return true;http.send(401,"application/json","{\"error\":\"authentication_required\"}");return false;}
String status(){DynamicJsonDocument d(2048);d["state"]=state;d["mode"]="hardware";d["boardValidated"]=BOARD_VALIDATED;d["error"]=fault;d["remaining"]=remaining;d["batteryPercent"]=nullptr;d["cellTemperatureC"]=nullptr;d["latest"]=serialized(latest);String s;serializeJson(d,s);return s;}
bool applyCommand(JsonVariant d,String &error){
 String action=d["action"]|"";
 if(action=="stop"){remaining=0;abortFlag=true;acquiring=false;timerAlarmDisable(timer);lightsOff();state="idle";return true;}
 if(action!="start"){error="unknown_action";return false;}
 if(acquiring || remaining>0){error="busy";return false;}
 int n=d["blocks"]|1,dt=d["intervalSec"]|3,du=d["dutyPercent"]|25,ma=d["ledMask"]|15;
 if(n<1||n>60||dt<3||dt>300||du<1||du>50||ma<0||ma>15){error="invalid_settings";return false;}
 if(!BOARD_VALIDATED && ma!=0){error="board_not_validated";return false;}
 // Tested plan is fixed. Changing frequencies requires new harmonic and analog-bandwidth validation.
 remaining=n;intervalSec=dt;duty=du;mask=ma;fault="";nextStart=millis();state="waiting";return true;
}
bool remote(const String &path,const String &body,String &response){
 if(String(CLOUD_URL).isEmpty() || WiFi.status()!=WL_CONNECTED || acquiring)return false;
 HTTPClient h;WiFiClient plain;WiFiClientSecure secure;String url=String(CLOUD_URL)+path;
 if(url.startsWith("https://")){if(String(CLOUD_CA_PEM).isEmpty())return false;secure.setCACert(CLOUD_CA_PEM);h.begin(secure,url);}
 else {if(!ALLOW_LAN_HTTP)return false;h.begin(plain,url);}
 h.setTimeout(1500);h.addHeader("X-Device-Key",CLOUD_DEVICE_KEY);h.addHeader("Content-Type","application/json");int code=body.isEmpty()?h.GET():h.POST(body);response=h.getString();h.end();return code==200;
}
void setup(){
 Serial.begin(115200);for(int p:LED){pinMode(p,OUTPUT);digitalWrite(p,LOW);}pinMode(CNV,OUTPUT);digitalWrite(CNV,LOW);SPI.begin(SCLK_PIN,MISO_PIN,-1,-1);
 bootId=String((uint32_t)esp_random(),HEX);WiFi.mode(WIFI_AP_STA);WiFi.softAP("AeroSense",AP_PASSWORD);
 if(strlen(WIFI_SSID))WiFi.begin(WIFI_SSID,WIFI_PASSWORD);
 configTime(0,0,"pool.ntp.org");LittleFS.begin(false);
 xTaskCreatePinnedToCore(sampleTask,"adc",4096,nullptr,20,&sampler,1);timer=timerBegin(0,80,true);timerAttachInterrupt(timer,&timerISR,true);timerAlarmWrite(timer,250,true);
 const char* headers[]={"X-Aero-Key"};http.collectHeaders(headers,1);
 http.on("/api/status",HTTP_GET,[]{if(auth())http.send(200,"application/json",status());});
 http.on("/api/command",HTTP_POST,[]{if(!auth())return;DynamicJsonDocument d(1024);String err;if(deserializeJson(d,http.arg("plain"))){http.send(400,"application/json","{\"error\":\"invalid_json\"}");return;}bool ok=applyCommand(d.as<JsonVariant>(),err);http.send(ok?200:409,"application/json",ok?"{\"ok\":true}":"{\"error\":\""+err+"\"}");});
 http.on("/api/raw.csv",HTTP_GET,[]{if(!auth())return;if(acquiring){http.send(409,"text/plain","busy");return;}http.setContentLength(CONTENT_LENGTH_UNKNOWN);http.send(200,"text/csv","");http.sendContent("sample,time_us,adc_counts\n");for(int i=0;i<count;i++){http.sendContent(String(i)+","+String((uint32_t)(ts[i]-ts[0]))+","+String(raw[i])+"\n");}http.sendContent("");});
 http.onNotFound([]{String p=http.uri();if(p=="/")p="/index.html";if(p.indexOf("..")>=0||!LittleFS.exists(p)){http.send(404,"text/plain","Not found");return;}File f=LittleFS.open(p,"r");http.streamFile(f,p.endsWith(".js")?"application/javascript":p.endsWith(".css")?"text/css":"text/html");f.close();});http.begin();
 Serial.println("AeroSense AP http://192.168.4.1; upload filesystem before opening UI.");
}
void loop(){
 if(completed)finishBlock();
 // Upload retries precede the next acquisition; never discard an unacknowledged result.
 static uint32_t poll=0;
 if(!acquiring && millis()-poll>2000){poll=millis();String response;
  if(outCount){if(remote("/api/device/result",outbox[0],response)){for(int k=1;k<outCount;k++)outbox[k-1]=outbox[k];outCount--;}}
  if(remote("/api/device/poll","",response)){DynamicJsonDocument d(2048);if(!deserializeJson(d,response)&&!d["command"].isNull()){
   auto c=d["command"];String id=c["id"]|"";String err;
   if(id!=lastCommand){bool ok=applyCommand(c,err);lastCommand=id;DynamicJsonDocument ack(512);ack["id"]=id;ack["ok"]=ok;ack["error"]=err;lastAck="";serializeJson(ack,lastAck);}
   remote("/api/device/ack",lastAck,response);
  }}
 }
 http.handleClient();
 if(!acquiring&&remaining>0&&(int32_t)(millis()-nextStart)>=0){
  // Finite local sessions continue without cloud. Latest block remains locally downloadable.
  if(outCount>=8){fault="upload_queue_full";state="fault";remaining=0;}else beginBlock();
 }
 delay(1);
}

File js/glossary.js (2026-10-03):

/**
 * AeroSense glossary — accessible term popovers.
 * Short, plain-language definitions for readers throughout the wiki.
 */
/* The decorative definition-orb geometry below is adapted from thinking-orbs,
 * src/engine/core.ts and src/engine/orbits.ts, by Jakub Antalik.
 * https://github.com/Jakubantalik/thinking-orbs
 *
 * MIT License
 * Copyright (c) 2026 Jakub Antalik
 *
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
 * THE SOFTWARE IS PROVIDED "AS IS", WITHOUT WARRANTY OF ANY KIND, EXPRESS OR
 * IMPLIED, INCLUDING BUT NOT LIMITED TO THE WARRANTIES OF MERCHANTABILITY,
 * FITNESS FOR A PARTICULAR PURPOSE AND NONINFRINGEMENT. IN NO EVENT SHALL THE
 * AUTHORS OR COPYRIGHT HOLDERS BE LIABLE FOR ANY CLAIM, DAMAGES OR OTHER
 * LIABILITY, WHETHER IN AN ACTION OF CONTRACT, TORT OR OTHERWISE, ARISING FROM,
 * OUT OF OR IN CONNECTION WITH THE SOFTWARE OR THE USE OR OTHER DEALINGS IN THE
 * SOFTWARE.
 */
(function () {
  "use strict";

  var DEFINITIONS = {
    voc: {
      term: "VOC",
      def: "Volatile organic compound — a carbon-containing chemical that readily enters the gas phase at ambient conditions.",
    },
    mycotoxin: {
      term: "Mycotoxin",
      def: "A toxic secondary metabolite that some fungi can produce. Detecting mold growth is not the same measurement as quantifying a mycotoxin.",
    },
    sds: {
      term: "SDS",
      def: "Safety Data Sheet — a supplier document describing chemical hazards, handling, and emergency information for a substance.",
    },
    sop: {
      term: "SOP",
      def: "Standard operating procedure — an institution-approved written method for performing a task safely and consistently.",
    },
    rg: {
      term: "Risk group",
      def: "A classification of biological agents by the relative risk they pose; institutional assignment must be confirmed locally.",
    },

    or: {
      term: "Odorant receptor (OR)",
      def: "An insect receptor protein that helps turn binding by an odor molecule into a cellular signal, usually in partnership with Orco.",
    },
    orco: {
      term: "Orco",
      def: "Odorant receptor co-receptor — an insect co-receptor that partners with ORs to form ligand-gated ion channels.",
    },
    drosophila: {
      term: "Drosophila",
      def: "A genus of flies. The fruit fly Drosophila melanogaster is a source of well-studied odorant receptors and inspired the project's sensing and coding designs.",
    },
    vuaa1: {
      term: "VUAA1",
      def: "A synthetic compound used to activate Orco-containing insect odorant-receptor channels; useful as a pathway control.",
    },
    hek293t: {
      term: "HEK293T",
      def: "A human embryonic kidney cell line commonly used for heterologous protein expression.",
    },
    gcamp6: {
      term: "GCaMP6",
      def: "A genetically encoded fluorescent calcium indicator used to report intracellular Ca²⁺ changes.",
    },
    gcamp: {
      term: "GCaMP",
      def: "A family of genetically encoded fluorescent reporters that become brighter when calcium inside a cell rises.",
    },
    "delta-f-over-f0": {
      term: "ΔF/F₀",
      def: "Relative fluorescence change — the change in fluorescence divided by a baseline fluorescence level.",
    },
    obp: {
      term: "OBP",
      def: "Odorant-binding protein — a soluble protein that can bind and help transport hydrophobic odorants.",
    },
    al: {
      term: "AL",
      def: "Antennal lobe — the insect brain center that receives primary olfactory input and performs early odor processing.",
    },
    pn: {
      term: "PN",
      def: "Projection neuron — a neuron that relays processed olfactory information from the antennal lobe to higher centers.",
    },
    mb: {
      term: "MB",
      def: "Mushroom body — an insect brain structure involved in olfactory learning, memory, and sparse odor coding.",
    },
    kc: {
      term: "KC",
      def: "Kenyon cell — a mushroom-body neuron that typically participates in sparse, high-dimensional odor representations.",
    },
    mbon: {
      term: "MBON",
      def: "Mushroom body output neuron — a neuron that reads mushroom-body activity and contributes to behavioral decisions.",
    },
    "lateral-inhibition": {
      term: "Lateral inhibition",
      def: "A circuit motif in which active units suppress neighbors, often increasing contrast between signals.",
    },
    "sparse-coding": {
      term: "Sparse coding",
      def: "A representation strategy in which only a small fraction of units are strongly active for a given input.",
    },
    lsh: {
      term: "LSH",
      def: "Locality-sensitive hashing — a method that maps similar inputs to nearby codes with high probability.",
    },
    snn: {
      term: "SNN",
      def: "Spiking neural network — a neural model that communicates with discrete spike events over time.",
    },
    ali: {
      term: "ALI",
      def: "Air–liquid interface — a culture or sampling setup where cells contact gas above a liquid medium.",
    },
    fdm: {
      term: "FDM",
      def: "Frequency-division multiplexing — assigning distinct carrier frequencies so multiple optical channels can share a detector path.",
    },
    dlia: {
      term: "DLIA",
      def: "Digital lock-in amplifier — a digital method that extracts a signal at a known reference frequency while rejecting other noise.",
    },
    tia: {
      term: "TIA",
      def: "Transimpedance amplifier — a circuit that converts a small input current into a usable output voltage.",
    },
    adc: {
      term: "ADC",
      def: "Analog-to-digital converter — hardware that samples an analog voltage and encodes it as a digital value.",
    },
    cfd: { term: "CFD", def: "Computational fluid dynamics — numerical calculations of fluid motion, used here to compare airflow and pressure through the reader." },
    "monte-carlo": { term: "Monte Carlo simulation", def: "A numerical method that follows many randomly sampled events. In the optical model, simulated photon paths estimate how much light reaches the detector." },
    fluence: { term: "Optical fluence", def: "Light energy incident per unit area, integrated over time. In a steady optical calculation, the corresponding fluence rate describes light power per unit area arriving from all directions." },
    "quantum-yield": { term: "Fluorescence quantum yield", def: "The ratio of emitted fluorescence photons to absorbed excitation photons. It describes emission efficiency, not how much light the detector collects." },
    responsivity: { term: "Photodiode responsivity", def: "Photocurrent produced per unit of incident optical power, usually expressed in amperes per watt. It depends on the wavelength of the light." },
    ldo: { term: "LDO", def: "Low-dropout regulator — a circuit that maintains a regulated supply voltage with a small required voltage difference between input and output." },
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

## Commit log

2026-09-28 Update AeroSense wiki
    [01_integrated_body.stl, 02_service_tray.stl, 03_hinged_lid.stl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]
2026-10-03 wiki update
    [Lock_NTHU-TEST_BOARD_V1-0929_view_locked.brd]
